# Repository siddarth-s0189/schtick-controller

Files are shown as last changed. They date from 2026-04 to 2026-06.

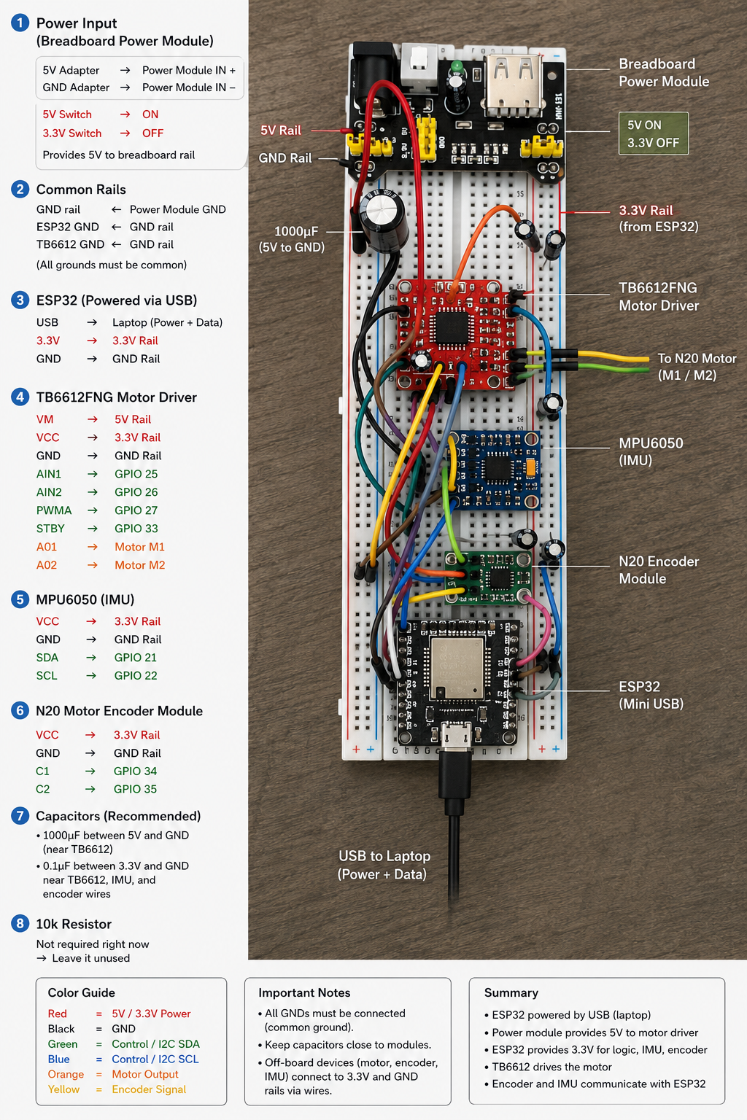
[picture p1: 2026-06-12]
assembly/circuit_diagram_rough.png

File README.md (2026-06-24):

# SCHTICK

A reaction wheel inverted pendulum built using an ESP32, MPU6050, and custom reaction wheel assembly.

SCHTICK Demo

---

## Overview

SCHTICK began as an attempt to stabilize a reaction wheel inverted pendulum using modern control techniques.

The original workflow was:

1. System Identification
2. State-Space Modeling
3. LQR Control
4. PID Control
5. Limit Cycle Exploration

While simulation results were promising, real-world hardware constraints revealed several practical limitations involving actuator authority, parameter estimation uncertainty, and model mismatch.

This repository documents both the successes and failures encountered during development.

---

## Hardware

* ESP32
* MPU6050 IMU
* DC Motor + Reaction Wheel
* H-Bridge Motor Driver
* Custom 3D Printed Structure

Additional details can be found in:

* `parts/`
* `assembly/`

---

## Repository Structure

```text
docs/                   Project documentation

matlab/
├── sysid/
├── modeling/
├── lqr/
├── pid/

src/
├── sysid/
├── control/
├── lqr/
├── pid/
├── limit_cycle/
```

---

## Results

### LQR

* Successful in simulation
* Failed to consistently stabilize hardware

### PID

* Achieved short-duration balancing (~3 seconds)
* Revealed actuator authority limitations

### Limit Cycles

* Currently being explored as an alternative control strategy

---

## Documentation

Detailed project notes are available in:

* `docs/control_artifacts.md`
* `docs/system_identification.md`
* `docs/modeling.md`
* `docs/lqr_controller.md`
* `docs/pid_controller.md`
* `docs/limit_cycling.md`
* `docs/lessons_learned.md`
* `docs/future_directions.md`

---

## Key Takeaway

The hardest part of this project was not designing the controller.

It was understanding why mathematically correct controllers behaved differently once real hardware constraints entered the picture.

---

## License

MIT License

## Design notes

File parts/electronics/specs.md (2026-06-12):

### BOM
1. N20 Motor (with encoder); 5V 500RPM rated.
2. TB6612FNG Motor Driver
3. MPU6050 with right-angled header pins.
4. ESP32
5. Capacitors 1x 1000uF and 2-3x 0.1uF
6. Breadboard Power Module
7. Breadboard
8. Jumper Wires
9. Solder Kit

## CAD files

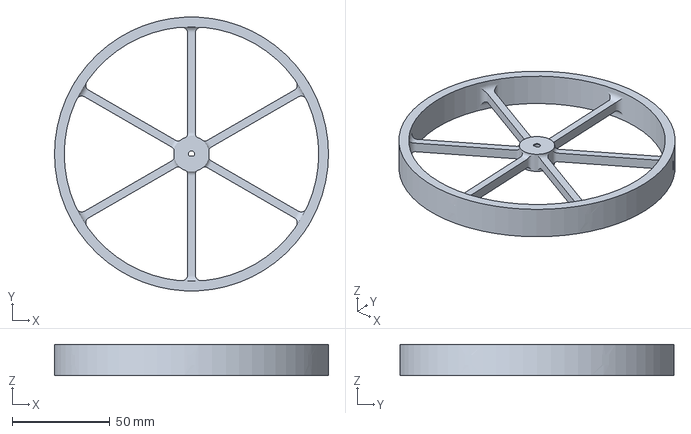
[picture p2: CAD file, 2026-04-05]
parts/flywheel/fly_wheel.3mf
140.0 x 140.0 x 16.0 mm

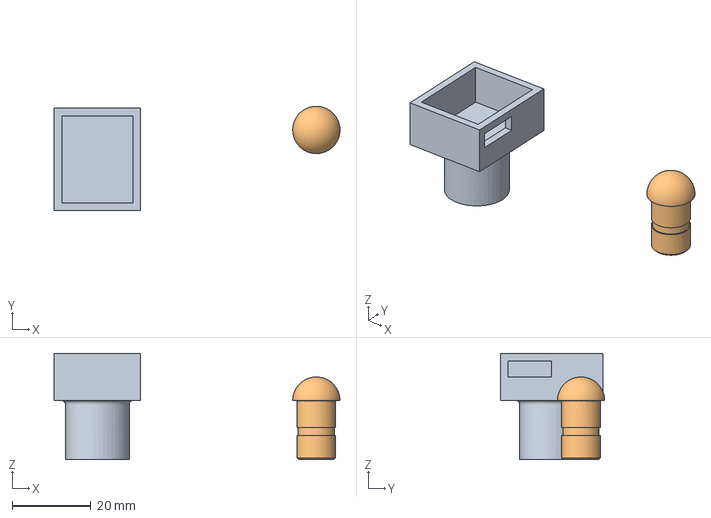
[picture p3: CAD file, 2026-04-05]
parts/imu_mount/imu_mount.3mf
72.5 x 26.5 x 27.0 mm
imu_mount.STL
mushroom_pivot.STL

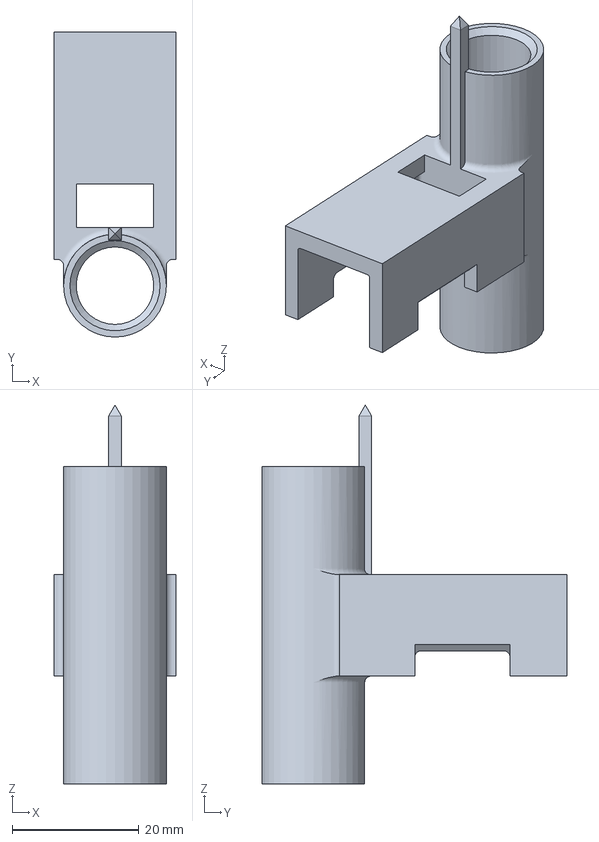
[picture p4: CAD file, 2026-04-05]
parts/motor_mount/motor_mount.3mf
19.2 x 48.1 x 59.7 mm

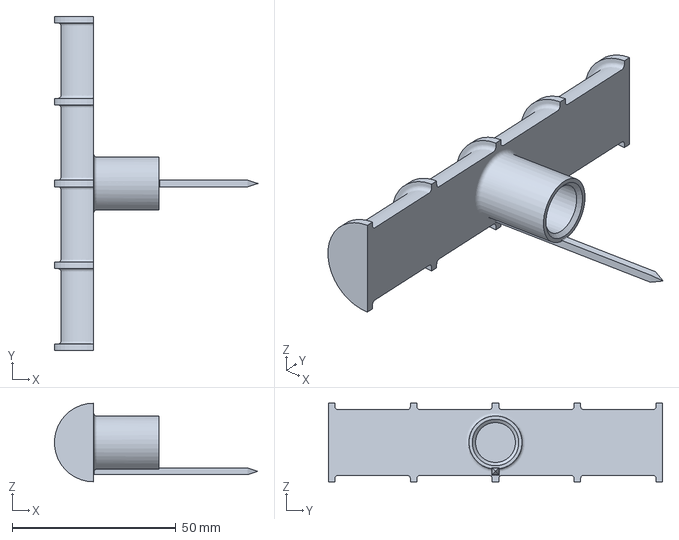
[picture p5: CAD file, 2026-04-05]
parts/pivot/cradle_pivot.3mf
62.0 x 102.0 x 24.0 mm

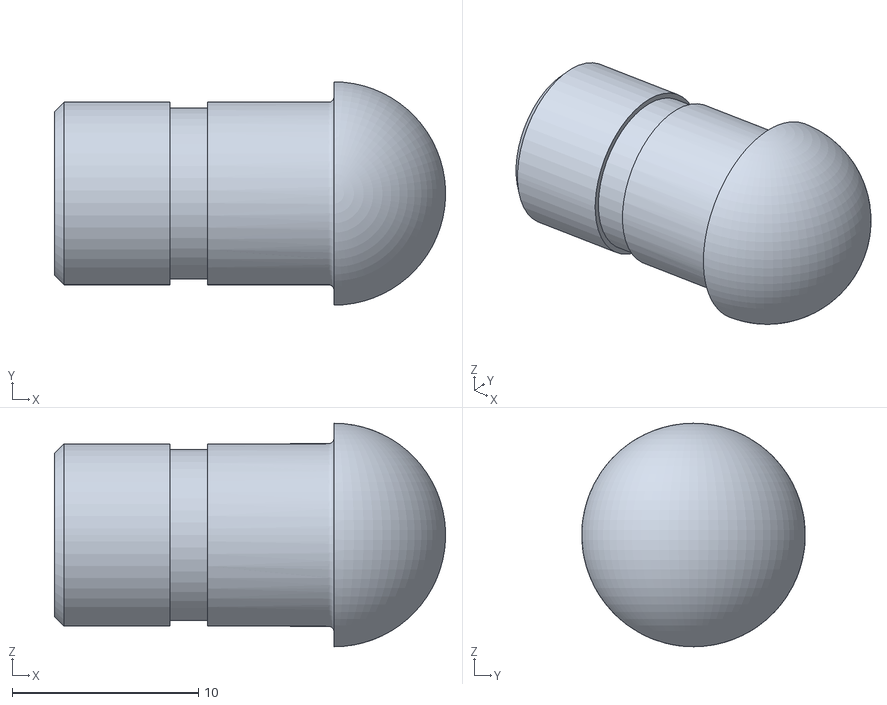
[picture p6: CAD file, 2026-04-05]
parts/scrapped/mushroom_pivot.STL
21.0 x 12.0 x 12.0

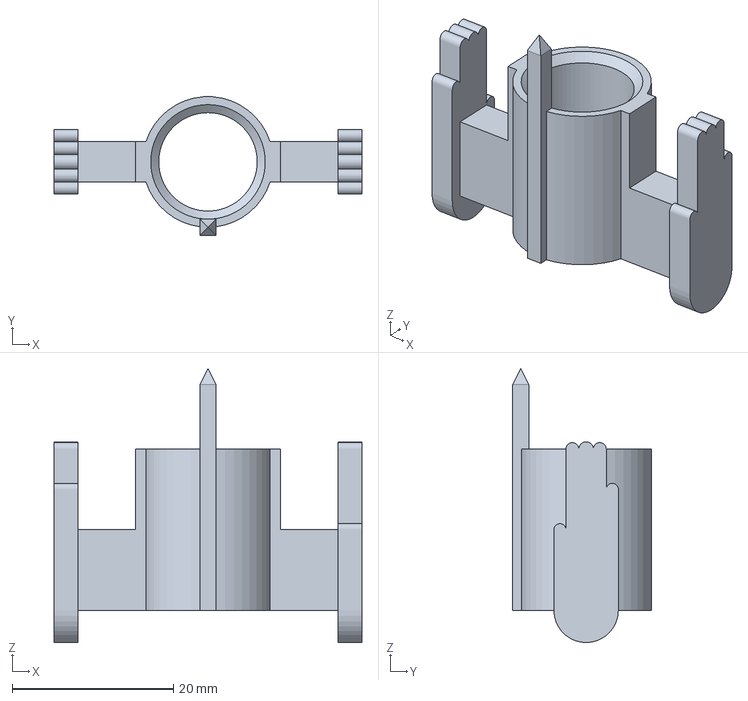
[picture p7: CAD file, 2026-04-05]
parts/scrapped/stopper.3mf
38.2 x 17.2 x 34.0 mm

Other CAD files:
parts/flywheel/fly_wheel.STL
parts/imu_mount/imu_mount.STL
parts/motor_mount/motor_mount.STL
parts/pivot/cradle_pivot.STL
parts/scrapped/stopper.STL

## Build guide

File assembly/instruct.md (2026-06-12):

### Mechanical Assembly (the way I did it)
1. Press fit pivot, motor mount and IMU mount onto the carbon fiber tube, use some form of adhesion if necessary. Ensure alignment (especially pivot with motor mount) is perfect before any form of attempt at adhesion (which is why I avoided it). Even the slightest deviation can affect results of control.
2. Wrap motor with one layer of foam tape. Insert N20 motor (500 RPM, 6V) into the motor mount slot, encoder facing down. Zip tie motor down the center to prevent movement. Attach Flywheel to motor shaft.
3. Place IMU (with soldered right-angle header pins) into the IMU mount. The slot design of the IMU mount was an oversight paired with the fact that I soldered the header pins facing the opposite way; I had to shave off that side of the mount and added a thick foam block to work around my underwhelming design. You don't have to do this, just print a more functional mount in the first place. IMU was secured using foam tape and scotch tape.

### Electronic Assembly (the way I did it)
1. Soldering: the IMU pins to header pins, the TB6612FNG motor driver module to header pins to insert into breadboard and the motor encoder wires if you're sure they won't break down when you're coding like it frustratingly did for me. For the motor encoder wires connection, I just twist and tape it with a jumper wire after ripping off one side to expose the wire.
2. Connect the wiring as shown in the circuit diagram.
3. Not shown in diagram but AIN1 and AIN2 connects to M1 and M2 on motor encoder respectively. 
4. Power: connect ESP32 to laptop power. In breadboard power module, turn on 5V but turn off 3.3V line. 5V line is powered by a wall adapter to barrel jack source. 3.3V line powered via ESP32. All components use 3.3V except for motor. Circuit diagram goes in detail.
5. It is critical you use enough wire length to have some slack when connected to the reaction wheel inverted pendulum body. 
6. In the circuit diagram, visuals might be innaccurate (as its unverified AI generation), however you can trust the text written connections in the same image.

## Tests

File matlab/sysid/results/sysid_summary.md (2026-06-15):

 ========================= SUMMARY ========================= 
## Test A PWM-RPM Relationship
 ### Goal: 
 1. Determine relationship between RPM at motor shaft and the PWM input supplied as current. Ideally, the relationship must be a linear fit: y = mx + b
 2. Determine motor dead zone (initial region where PWM increases but RPM is still at 0), motor gain (ie.'m' = rate at which RPM increases with PWM), saturation point (point at which motor gain starts to decrease)
 ### Procedure:
 Hold pendulum still as PWM is increased incrementally and encoder reads counts (previous experiments allowed us to determine estimate of counts/revolution).
 ### Results:
 Dead zone ≈ PWM 50 
 Motor gain = 1.1580 RPM/PWM 
 Offset = -20.3859 RPM
 Saturation: not found
 ### Figure Analysis:
 1. Linear Fit: Orange line is the best-fit straight line, Blue line is the plotted data. After initial dead zone, motor gain matches near-perfectly with the optimal linear fit. This validates the y = mx + b relationshiop very well. 
 2. Local Slope: Graph plots the derivative of RPM with respect to PWM against PWM. Let's us see the variation in motor gain zoomed in. After initial dead zone wake (huge spike), motor gain settles and does not drop at the end, which further confirms the absence of saturation within the PWM limits. 

## Test B Motor Response
 ### Goal:
 1. Startup characterization: allows us the understand how startup from 0 PWM influences motor response as opposed to when the motor/wheel already has angular momentum. 
 2. Directly estimate maximum available corrective torque by reversing from 255 to -255 PWM (the two extremes) and vice versa.
 3. Doing the full reversal in both opposite directions allows us to infer directional assymmetry if any. 
 ### Procedure:
 Hold pendulum still in fixed position, only wheel must move freely. Motor starts and rises PWM to -255, does full rise to +255 and reverses back to -255. Then, coasts down back to 0 PWM. PWM delta rate constant. Once wheel settles, experiment is over. Point is to observe how RPM changes with time when PWM change over time is kept at a constant rate, aka motor response. 
 ### Results:
 Steady-state RPM : -276.67 
 63% Rise Time : 300.0 ms 
 Cross Time (+-) : 140.0 ms 
 Cross Time (-+) : 160.0 ms
 Saturation (confirmed verdict): not present for practical purposes
 ### Figure Analysis:
 1. Full Response: provides a bird's eye view of the entire experiment. Startup from 0 to -255 PWM, then full reversal from -255 to 255 PWM and opposite reversal back to -255 PWM. Then, coast down back to 0 PWM. PWM is always incrementally (by 5) changed at a constant rate. Goal is to observe how RPM changes with time, as motor response is a factor. 
 2. Startup Characterization: ideally for a first-order motor, RPM at 63.2% power = 0.632 * Steady-state RPM. Plugging in -276.67, we should hit 174.8 RPM approx. at 63.2% power (1 - 1/e is where the value comes from). Inferred from the graph, -175 rpm is achieved 300ms after startup. Hence time constant τ = 0.3s. While slow and non-ideal for a self-stabilizing inverted pendulum, it is due to the heavy and high MOI wheel attached to the motor. 
 3. Direction asymmetry is present but minimal. Difference in cross time in full-reversals in opposite directions is 20ms. Relative error is approx. 13%.
 4. Graphs suggest that reversal is not linear; motor torque first halts existing momentum and then, accelerates wheel opposite direction.

## Test C Pendulum Free Response
 ### Goal:
 1. Estimate unstable pole λ, which quantifies how quickly the pendulum diverges from upright equilibrium.
 2. Estimate the effective pendulum length L_eff from experimental data. L_eff is not the geometric pivot-COM distance, it is instead the equivalent simple-pendulum length that reproduces the measured dynamics.
 3. Validate the IMU angle estimation pipeline (accelerometer scaling, gyro scaling, complementary filter, and calibration).
 ### Procedure:
 Hold pendulum still at a small angle (0-5 degrees) close to vertical as calibration occurs, then let it fall until it reaches around 25-35 degrees when you catch it with your hand without letting it impact on the ground. Ensure no obstruction while it is falling or any momentum introduced by hand as you release it. Goal is to observe its natural free fall. Once you catch it, keep the pendulum still until the timer runs out.
 ### Results:
 Mean accelerometer magnitude: 1.024 g
 Accelerometer saturation events: 0 / 499 samples
 Residual gyro bias: −1.287 deg/s
 Estimated drift over 5 s: −6.44 deg
 Auto-detected fall window: 0.850–1.270 s
 Initial angle (θ₀): 0.752°
 Unstable pole (λ): 8.115 rad/s
 Effective length (L_eff): 0.149 m
 Characteristic divergence time (1/λ): 0.123 s
 ### Figure Analysis:

## Test 4 Balance Region 
 ### Goal:
 1. Verify that reaction-wheel torque produces corrective motion in the expected direction.
 2. Estimate corrective authority near the upright operating region.
 3. Observe behaviour during sustained corrective action.
 4. Assess suitability of the actuator for closed-loop stabilization.
 ### Procedure:
 This experiment uses a HOLD-REACT-COAST serial phase approach. In the HOLD phase, you must keep the pendulum appromixately upright. Donot keep it rigid but hold as loose as you can while maintaining its vertical positioning. Just as it is about to transition into REACT phase, let the pendulum fall in whatever direction is it naturally leaning at, then stop it around 20-30 degrees by catching it with your hand. Let the rest of the expeirment complete. If motor authority is strong enough, pendulum might rise back to vertical, or it can visually appear not to fight the fall at all. If the latter occurs (as it did for me), it does not necessarily mean something is wrong. It's still good data.  
 ### Results: 
 Disturbance PWM: 200
 Open-loop divergence coefficient (hold phase): 1.497 s⁻¹
 Time to reach 10° from 1°: 1.538 s
 Initial corrective angular acceleration: −39.60 deg/s²
 Peak angular velocity during correction: 26.62 deg/s
 Corrective authority: −0.1980 deg/s²/PWM
 ### Figure Analysis:

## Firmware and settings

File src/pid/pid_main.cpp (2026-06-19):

#include <Arduino.h>

#include "control/state_estimator.h"
#include "pid/pid_balance.h"
#include "control/motor_driver.h"
#include "control/sensors.h"

void pidSetup()
{
    Serial.begin(115200);

    sensorsSetup();

    motorDriverSetup();

    Serial.println("PID controller started");
}

void pidLoop()
{
    sensorsUpdate();

    StateVector x =
        estimateState();

    float pwm =
        computePID(
            x.theta,
            x.thetaDot);

    setMotorPWM(pwm);

    delay(5);
}

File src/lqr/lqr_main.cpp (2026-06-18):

#include <Arduino.h>

#include "control/state_estimator.h"
#include "lqr/lqr_balance.h"
#include "control/motor_driver.h"
#include "control/sensors.h"

float applyDeadzoneCompensation(float u)
{
    const float DEADZONE = 50.0f;
    const float EPSILON  = 5.0f;

    if (fabs(u) < EPSILON)
    {
        return 0.0f;
    }

    if (u > 0.0f)
    {
        return u + DEADZONE;
    }
    else
    {
        return u - DEADZONE;
    }
}

void lqrSetup()
{
    Serial.begin(115200);

    sensorsSetup();

    motorDriverSetup();

    Serial.println(
        "theta,thetaDot,wheelRPM,rawPWM,clippedPWM");
}

void lqrLoop()
{
    sensorsUpdate();

    StateVector x =
        estimateState();

    float rawPWM =
        computeLQR(
            x.theta,
            x.thetaDot,
            x.wheelSpeed);

    float pwm =
        applyDeadzoneCompensation(rawPWM);

    setMotorPWM(pwm);

    Serial.print(rawPWM);
    Serial.print(",");

    Serial.println(pwm);

    delay(5);
}

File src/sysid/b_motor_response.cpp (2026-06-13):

// ============================================
// TEST 2 : MOTOR STEP RESPONSE
//
// Measures:
// - startup characterization
// - direction symmetry
// - reversal response
// - spin-down response
//
// CSV Output:
// time_ms,pwm,rpm
// ============================================

#include <Arduino.h>

// --------------------------------------------
// MOTOR PINS
// --------------------------------------------

#define AIN1 25
#define AIN2 26
#define PWMA 27

// --------------------------------------------
// ENCODER PINS
// --------------------------------------------

#define ENCODER_A 34
#define ENCODER_B 35

// --------------------------------------------
// PWM CONFIG
// --------------------------------------------

static const int pwmChannel = 0;
static const int pwmFreq = 20000;
static const int pwmResolution = 8;

// --------------------------------------------
// ENCODER VARIABLES
// --------------------------------------------

static volatile long encoderCount = 0;

static const float countsPerRev = 203.96f;

static long lastCount = 0;
static unsigned long lastRPMTime = 0;

static float rpm = 0.0f;

// --------------------------------------------
// TEST TIMING
// --------------------------------------------

enum TestState
{
    WAIT_AT_ZERO,
    FORWARD,
    REVERSE,
    FORWARD_AGAIN,
    COAST_DOWN,
    FINISHED
};

static TestState state = WAIT_AT_ZERO;

static unsigned long stateStartTime = 0;

// --------------------------------------------
// ENCODER ISR
// --------------------------------------------

static void IRAM_ATTR encoderISR()
{
    int b = digitalRead(ENCODER_B);

    if (b == HIGH)
    {
        encoderCount++;
    }
    else
    {
        encoderCount--;
    }
}

// --------------------------------------------
// MOTOR CONTROL
// --------------------------------------------

static void setMotor(int pwm)
{
    if (pwm > 0)
    {
        digitalWrite(AIN1, HIGH);
        digitalWrite(AIN2, LOW);
    }
    else if (pwm < 0)
    {
        digitalWrite(AIN1, LOW);
        digitalWrite(AIN2, HIGH);
        pwm = -pwm;
    }
    else
    {
        digitalWrite(AIN1, LOW);
        digitalWrite(AIN2, LOW);
    }

    ledcWrite(pwmChannel, pwm);
}

// --------------------------------------------
// SETUP
// --------------------------------------------

void motorResponseSetup()
{
    // serial

    Serial.begin(115200);

    // motor

    pinMode(AIN1, OUTPUT);
    pinMode(AIN2, OUTPUT);

    ledcSetup(
        pwmChannel,
        pwmFreq,
        pwmResolution
    );

    ledcAttachPin(
        PWMA,
        pwmChannel
    );

    // encoder

    pinMode(ENCODER_A, INPUT_PULLUP);
    pinMode(ENCODER_B, INPUT_PULLUP);

    attachInterrupt(
        digitalPinToInterrupt(ENCODER_A),
        encoderISR,
        RISING
    );

    stateStartTime = millis();

    Serial.println();
    Serial.println("time_ms,pwm,rpm");
}

// --------------------------------------------
// RPM UPDATE
// --------------------------------------------

static void updateRPM()
{
    unsigned long now = millis();

    if (now - lastRPMTime >= 20)
    {
        noInterrupts();
        long currentCount = encoderCount;
        interrupts();

        long deltaCount =
            currentCount - lastCount;

        float dt =
            (now - lastRPMTime) / 1000.0f;

        float revs =
            (float)deltaCount /
            countsPerRev;

        rpm =
            (revs / dt) * 60.0f;

        lastCount = currentCount;
        lastRPMTime = now;
    }
}

// --------------------------------------------
// TEST SEQUENCE
// --------------------------------------------

static int commandedPWM = 0;

static void updateStateMachine()
{
    unsigned long elapsed =
        millis() - stateStartTime;

    switch (state)
    {
        case WAIT_AT_ZERO:

            commandedPWM = 0;

            if (elapsed >= 1000)
            {
                state = FORWARD;
                stateStartTime = millis();
            }

            break;

        case FORWARD:

            commandedPWM = 255;

            if (elapsed >= 2000)
            {
                state = REVERSE;
                stateStartTime = millis();
            }

            break;

        case REVERSE:

            commandedPWM = -255;

            if (elapsed >= 2000)
            {
                state = FORWARD_AGAIN;
                stateStartTime = millis();
            }

            break;

        case FORWARD_AGAIN:

            commandedPWM = 255;

            if (elapsed >= 2000)
            {
                state = COAST_DOWN;
                stateStartTime = millis();
            }

            break;

        case COAST_DOWN:

            commandedPWM = 0;

            if (elapsed >= 2000)
            {
                state = FINISHED;
                stateStartTime = millis();

                Serial.println("TEST COMPLETE");
            }

            break;

        case FINISHED:

            commandedPWM = 0;

            break;
    }

    setMotor(commandedPWM);
}

// --------------------------------------------
// LOOP
// --------------------------------------------

void motorResponseLoop()
{
    updateRPM();

    updateStateMachine();

    static unsigned long lastLog = 0;

    unsigned long now = millis();

    if (now - lastLog >= 20)
    {
        Serial.print(now);
        Serial.print(",");

        Serial.print(commandedPWM);
        Serial.print(",");

        Serial.println(rpm);

        lastLog = now;
    }
}

// // ============================================
// // TEST 2 : MOTOR STEP RESPONSE
// //
// // Measures:
// // - startup characterization
// // - direction symmetry
// // - reversal response
// // - spin-down response
// //
// // CSV Output:
// // time_ms,pwm,rpm
// // ============================================

// #include <Arduino.h>

// // --------------------------------------------
// // MOTOR PINS
// // --------------------------------------------

// #define AIN1 25
// #define AIN2 26
// #define PWMA 27

// // --------------------------------------------
// // ENCODER PINS
// // --------------------------------------------

// #define ENCODER_A 34
// #define ENCODER_B 35

// // --------------------------------------------
// // PWM CONFIG
// // --------------------------------------------

// const int pwmChannel = 0;
// const int pwmFreq = 20000;
// const int pwmResolution = 8;

// // --------------------------------------------
// // ENCODER VARIABLES
// // --------------------------------------------

// volatile long encoderCount = 0;

// const float countsPerRev = 203.96f;

// long lastCount = 0;
// unsigned long lastRPMTime = 0;

// float rpm = 0.0f;

// // --------------------------------------------
// // TEST TIMING
// // --------------------------------------------

// enum TestState
// {
//     WAIT_AT_ZERO,
//     FORWARD,
//     REVERSE,
//     FORWARD_AGAIN,
//     COAST_DOWN,
//     FINISHED
// };

// TestState state = WAIT_AT_ZERO;
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

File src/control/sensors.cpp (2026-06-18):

#include "sensors.h"
#include "filters.h"

#include <Arduino.h>
#include <Wire.h>
#include <math.h>

#define MPU_ADDR 0x68

#define ENCODER_A 34
#define ENCODER_B 35

static const float COUNTS_PER_REV = 203.96f;

static volatile long encoderCount = 0;

static int16_t axRaw;
static int16_t ayRaw;
static int16_t azRaw;

static int16_t gxRaw;
static int16_t gyRaw;
static int16_t gzRaw;

static float gxBias = 0.0f;

static float mountingOffsetDeg = 0.0f;

static float gyroXDegS = 0.0f;

static float wheelRPM = 0.0f;

static unsigned long lastUpdateMs = 0;

static long lastEncoderCount = 0;

static ComplementaryFilter compFilter(0.98f);

static float angleDeg = 0.0f;

static void IRAM_ATTR encoderISR()
{
    int b = digitalRead(ENCODER_B);

    if (b == HIGH)
    {
        encoderCount++;
    }
    else
    {
        encoderCount--;
    }
}

static void readMPU()
{
    Wire.beginTransmission(MPU_ADDR);
    Wire.write(0x3B);
    Wire.endTransmission(false);

    Wire.requestFrom(MPU_ADDR, 14, true);

    axRaw = (Wire.read() << 8) | Wire.read();
    ayRaw = (Wire.read() << 8) | Wire.read();
    azRaw = (Wire.read() << 8) | Wire.read();

    Wire.read();
    Wire.read();

    gxRaw = (Wire.read() << 8) | Wire.read();
    gyRaw = (Wire.read() << 8) | Wire.read();
    gzRaw = (Wire.read() << 8) | Wire.read();
}

void sensorsSetup()
{
    Wire.begin();

    Wire.beginTransmission(MPU_ADDR);
    Wire.write(0x6B);
    Wire.write(0x00);
    Wire.endTransmission(true);

    Wire.beginTransmission(MPU_ADDR);
    Wire.write(0x1B);
    Wire.write(0x18);
    Wire.endTransmission(true);

    Wire.beginTransmission(MPU_ADDR);
    Wire.write(0x1C);
    Wire.write(0x10);
    Wire.endTransmission(true);

    pinMode(ENCODER_A, INPUT_PULLUP);
    pinMode(ENCODER_B, INPUT_PULLUP);

    attachInterrupt(
        digitalPinToInterrupt(ENCODER_A),
        encoderISR,
        RISING);

    delay(100);

    float sum = 0.0f;

    for(int i = 0; i < 200; i++)
    {
        readMPU();

        sum += gxRaw;

        delay(5);
    }

    gxBias = sum / 200.0f;

    readMPU();

    mountingOffsetDeg =
        atan2f(
            (float)ayRaw,
            (float)azRaw)
        * 180.0f / PI;

    compFilter.reset(0.0f);

    lastUpdateMs = millis();
}

void sensorsUpdate()
{
    unsigned long now = millis();

    float dt =
        (now - lastUpdateMs) /
        1000.0f;

    if(dt <= 0.0f)
        return;

    lastUpdateMs = now;

    readMPU();

    gyroXDegS =
        (gxRaw - gxBias) /
        16.4f;

    float accelAngleDeg =
        atan2f(
            (float)ayRaw,
            (float)azRaw)
        * 180.0f / PI
        - mountingOffsetDeg;

    angleDeg =
        compFilter.update(
            accelAngleDeg,
            gyroXDegS,
            dt);

    noInterrupts();
    long currentCount = encoderCount;
    interrupts();

    long deltaCount =
        currentCount -
        lastEncoderCount;

    lastEncoderCount =
        currentCount;

    float revs =
        deltaCount /
        COUNTS_PER_REV;

    wheelRPM =
        (revs / dt) * 60.0f;
}

float getAngleDeg()
{
    return angleDeg;
}

float getGyroXDegS()
{
    return gyroXDegS;
}

float getWheelRPM()
{
    return wheelRPM;
}

// MPU6050 reading
// complementary filter
// encoder reading
// rpm calculation

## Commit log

2026-04-05 Add files for 3D-printed parts
    > .STL files are modelled using SOLIDWORKS
    > .3mf files were prepared for Bambu A1 Mini print job
    > fly_wheel --> produces the angular momentum required to keep pendulum stable
    > motor_mount --> houses the motor
    > cradle_pivot --> allow pendulum to freely pivot in one isolated axis
    > imu_mount --> houses the IMU (inertial measurement unit)
    > stopper --> designed to catch the pendulum from falling before the spinning wheels do to prevent damage to wheel & electronics
    > mushroom_mount --> legacy design scrapped due to project reframing from dual-axis to single-axis, kept for narrative consistency
    [cradle_pivot.3mf, cradle_pivot.STL, fly_wheel.3mf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]
2026-06-12 organized STL and 3MF (Bambu) files in a 'by part' format for ease of reference
    [cradle_pivot.3mf, cradle_pivot.STL, fly_wheel.3mf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]
2026-06-12 append parts with electronics and add assembly folder
    Appended parts/ with an electronics BOM with specs,,, Added an assembly folder which includes a circuit wiring diagram & guide along with a detailed assembly instruction .md file
2026-06-13 feat: system identification (TEST A)
    Test A desc: incremented PWM and observed change in RPM. used a countsperRev estimate by spinning reaction wheel 37 times and taking average. plotting RPM against PWM revealed significant motor deadz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
2026-06-13 feat: system identification (TEST B)
    Test B desc: pendulum body kept fixed while wheel spun in isolation. 0 to -255 to 255 to 0 PWM with delays in between each maneuver. Startup response characterized, steady-state RPM estimated, 63% rise time calculated and minor directional asymmetry noted. Yet confirmed RPM saturation not present approaching peak PWM.
    [b_motor_response.csv]
2026-06-14 feat: system identification (Test C)
    Test C desc: Pendulum released from near-vertical (~1°) and allowed to fall freely under gravity with motor off, caught by hand before floor impact (~25°). MPU6050 mounted with rotation axis on gx, a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
    [c_free_response_5.csv]
2026-06-14 feat: system identification (TEST D)
    **Test D desc:** Pendulum held near-vertical, motor off (OBSERVE, 2s), then reaction wheel driven at fixed PWM (−200) opposing instantaneous lean with 1° deadband (REACTIVE, 4s), then motor cut for free decay (COAST, 1s). Corrective direction confirmed — omega spiked +26 deg/s on activation, opposing the fall. Torque dropped to near-zero within ~0.5s as wheel reached steady-state RPM for that PWM (matches τ≈0.3s from Test B), after which angle stabilized passively at ~11-12° instead of returning to vertical. PWM column in CSV logged as 0 throughout REACTIVE despite motor active (per overview plot and omega response) — logging issue noted for co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
    [d_balance_region.csv]
2026-06-15 comprehensive sysID results markdown & validatory pre-sysID encoder flight check
2026-06-18 feat(modeling): add nonlinear dynamics and state-space model
    Implements the reaction-wheel pendulum dynamics and derives the linearized state-space representation used for controller design.
2026-06-18 feat(control): add sensing, estimation, and motor interfaces
    Implements sensor acquisition, filtering, state estimation, and motor control abstractions used by higher-level balancing controllers.
2026-06-18 feat(lqr): deploy embedded LQR controller [gains failed to stabilize craft irl]
    Integrates the LQR controller with state estimation, sensing, and motor control on the ESP32 platform. Hardware tests suggest model-plant mismatch, parameter estimation error, and actuator nonlinearities/saturation may have limited real-world performance.
    [lqr_main.cpp, main.cpp]
2026-06-19 docs(pid): add manual tuning reference workflow
    Provides a structured procedure and tuning log template for empirical PID gain selection on hardware. Attempt after PID auto-tune failed & scrapped.
2026-06-19 feat(pid): implement embedded PID controller [partial success, ~3-4s to capsize]
    Adds a hardware PID balancing controller and integrates it with the existing estimation, sensing, and motor control pipeline. Partial success with tuning gains, craft stabilized for ~3-4s but actuator torque saturation possibly the biggest limiting factor capsizing craft prematurely.
    [pid_main.cpp]
2026-06-24 feat: update README.md, add PID balance demo videos/GIFs, .gitignore, and furnish other files/folders
